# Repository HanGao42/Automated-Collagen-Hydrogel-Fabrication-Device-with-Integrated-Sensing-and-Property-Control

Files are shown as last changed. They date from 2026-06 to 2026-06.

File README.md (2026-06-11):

# Automated Hydrogel Production Platform

This project is a modular hardware and software platform for automated hydrogel production. It coordinates liquid loading, valve routing, syringe mixing, pH color checking, gantry deposition, UV curing, and buffer rehydration.

The active control software is in `Software/`. CAD and mechanical design files are kept separately in `CAD/`.

## System Summary

The platform is built from six hardware units:

1. Pumping unit
   - Four source syringes driven by stepper motors.
   - Aspirates source solutions at the start of an experiment.
   - Dispenses selected source solutions into the mixer during transfer.
   - Controlled by an Arduino Mega with a RAMPS 1.4 shield.

2. Outlet selector / valve lift unit
   - Uses stepper motors to lift and lower the outlet tube.
   - The outlet lift motion is implemented and calibrated.
   - The future outlet routing motor is reserved for later mechanical completion.

3. Mixing unit
   - Two mixer syringes, named Z and E1.
   - Rotary valve stages define the fluid path.
   - Stage 1 allows incoming solution to enter mixer syringe Z.
   - Stage 2 connects Z and E1 for push-pull mixing.
   - Stage 3 routes mixed material out for deposition.

4. pH camera unit
   - ESP32 camera reads hydrogel indicator color.
   - The software estimates pH from an RGB/HSV calibration table.
   - The default target pH is 7.4.
   - During control-flow pH checks, the camera takes five readings, averages them, reports the average, and turns off.

5. Deposition gantry
   - XY gantry draws a small circle while depositing material.
   - This spreads viscous material and prevents a cone-shaped pileup.
   - The gantry and mixer Z/E1 pumps share one Arduino Mega + RAMPS board, which allows synchronized gantry motion and E1 dispensing.

6. UV curing unit
   - Arduino Uno and relay module control UV power.
   - The controller accepts timed `start <seconds>` commands and immediate `stop`.

## Main Hardware

- Arduino Mega 2560 with RAMPS 1.4 shield for the four-syringe pumping unit.
- Arduino Mega 2560 with RAMPS 1.4 shield for the outlet lift / selector valve unit.
- Arduino Mega 2560 with RAMPS 1.4 shield for the deposition gantry and mixer syringe pumps.
- Arduino Uno with relay module for UV light control.
- Freenove ESP32-S3 WROOM camera board for pH color measurement.
- Stepper motors and stepper drivers for syringe plungers, valve motion, and XY gantry motion.
- Four source syringes on the pumping board.
- Two small mixer syringes on the gantry/mixing board.
- UV light source connected through the relay module.

## Default Serial Ports

The current software defaults are:

- Pumping unit: `COM9`
- Outlet selector / valve lift: `COM8`
- Deposition gantry and mixer pumps: `COM7`
- pH camera: `COM5`
- UV relay controller: `COM4`
- Baud rate: `115200`

These ports can be changed in the UI settings page or by command-line options.

## Software Structure

```text
Software/
  central_controller.py
  central_ui.py
  central_command_reference.txt
  ph_color_calibration_table.csv

  pumping_unit/
    syringe_pump_cli.py
    syringe_pump_ramps_controller/
      syringe_pump_ramps_controller.ino
    pumping_state.json

  mixing/
    outlet_flange_valve_controller.py
    outlet_flange_valve_ramps_controller/
      outlet_flange_valve_ramps_controller.ino
    outlet_flange_valve_state.json
    mixing_pump_state.json

  deposition_gantry/
    deposition_gantry_controller.py
    deposition_gantry_ramps_controller/
      deposition_gantry_ramps_controller.ino
    deposition_gantry_state.json

  ph_camera/
    esp32_ph_camera/
      esp32_ph_camera.ino

  uv_curing/
    uv_relay_controller.ino

  ML_model/
    validation and exploratory model files
```

## Code Logic

The project uses four software layers.

### Arduino firmware

The `.ino` files are the lowest hardware-control layer. They run directly on the Arduino or ESP32 boards and convert serial text commands into physical actions.

Firmware responsibilities:

- Configure RAMPS pins, stepper driver enable pins, STEP pins, and DIR pins.
- Generate motor pulses for syringe, valve, and gantry movement.
- Control the UV relay.
- Read camera RGB/HSV data on the ESP32.
- Return readable status lines and `OK` messages to Python.
- Handle emergency commands such as `STOP` and `UNLOCK`.

The Arduino firmware does not know the full hydrogel workflow. It only performs direct hardware actions requested by Python.

### Unit Python scripts

The unit Python scripts are the hardware wrapper layer. They send serial commands to one board and maintain software-side state where needed.

- `pumping_unit/syringe_pump_cli.py`
  - Controls the four source syringe pumps.
  - Stores syringe size and current volume in `pumping_state.json`.
  - Checks syringe capacity before aspirating or dispensing.

- `mixing/outlet_flange_valve_controller.py`
  - Controls outlet lift and mixing valve stages.
  - Stores known/unknown valve state in `outlet_flange_valve_state.json`.
  - Prevents relative stage moves when the saved valve state is unknown.

- `deposition_gantry/deposition_gantry_controller.py`
  - Controls XY gantry motion and mixer Z/E1 pump commands.
  - Stores gantry position in `deposition_gantry_state.json`.
  - Sends mixer pump commands and synchronized gantry-deposition commands to the gantry RAMPS board.

### Central controller

`Software/central_controller.py` is the orchestration layer. It does not directly toggle step pins. Instead, it calls the unit scripts or opens simple serial devices, then coordinates them into guarded workflow steps.

Central controller responsibilities:

- Parse high-level commands such as `flow transfer`, `flow mix-cycle`, `flow ph-check`, and `flow deposit`.
- Check pumping syringe limits before source transfer.
- Check mixer Z/E1 limits before mixing or deposition.
- Require the correct mixing valve stage before each flow step.
- Run some unit commands in software parallel when two boards must act together.
- Read and compare pH camera data against `ph_color_calibration_table.csv`.
- Stop pH camera automatically after flow pH checks.
- Control timed UV exposure through the UV relay Arduino.

Examples:

```bash
cd Software
python central_controller.py pump status
python central_controller.py flow transfer x 2
python central_controller.py flow mix-cycle
python central_controller.py flow ph-check
python central_controller.py flow deposit 1
python central_controller.py uv start 5
```

### Graphical UI

`Software/central_ui.py` is a Tkinter interface on top of `central_controller.py`.

The UI is not an independent control system. It builds central-controller commands, runs them as child Python processes, and displays their terminal output.

The UI has:

- Settings page for COM ports, pH gate values, and dry-run mode.
- Unit Test page for independent hardware checks.
- Control page for the ordered hydrogel workflow.
- Flow buttons arranged in experiment order.
- Live state panels for pumping, selector, mixing, deposition, UV, and pH.
- Terminal report panel showing command output.

## Gantry Control Details

The deposition gantry firmware is in:

```text
Software/deposition_gantry/deposition_gantry_ramps_controller/deposition_gantry_ramps_controller.ino
```

The gantry uses a classic CoreXY-style motion model with two coupled motors:

```text
Motor A = X + Y
Motor B = X - Y
```

In the firmware this appears as:

```cpp
long aSteps = xSteps + ySteps;
long bSteps = xSteps - ySteps;
```

This means an X/Y movement is first converted to X and Y step counts, then transformed into Motor A and Motor B step counts. The firmware then pulses each motor by the required number of steps.

Important implementation points:

- The gantry does not use the full Marlin firmware.
- It does not use the AccelStepper library for the gantry motion.
- The motion planning is custom and lightweight, using RAMPS STEP/DIR pins directly.
- The implementation is inspired by common 3D-printer/CNC motion concepts:
  - STEP pulse generation.
  - DIR pin direction control.
  - Soft travel limits.
  - A simple trapezoid-style acceleration profile.
  - Manual logical zero with `SETZERO`.

The STEP pulse function is intentionally simple:

```cpp
void pulseMotor(byte stepPin) {
  digitalWrite(stepPin, HIGH);
  delayMicroseconds(STEP_HIGH_US);
  digitalWrite(stepPin, LOW);
}
```

For each step, the firmware raises the STEP pin, waits a few microseconds so the stepper driver can detect the edge, then lowers the pin again.

The gantry firmware also handles synchronized commands:

- `PUMP PAIR ZS0.1 E1S-0.1`
  - Moves mixer syringes Z and E1 at the same time.
  - Used for push-pull mixing without the delay caused by sequential commands.

- `GANTRY DEPOSIT X30 Y30 R8 V0.5 N120 L1`
  - Draws a circular gantry path while dispensing from mixer syringe E1.
  - Used during deposition so the gantry and E1 syringe move together on the same RAMPS board.

## Production Workflow

The intended automated workflow is:

1. Fill the selected pumping syringe with source solution.
2. Move the mixing valve to Stage 1.
3. Transfer solution from the pumping unit into mixer syringe Z.
4. Disable pumping motors if they are no longer needed, to reduce heating.
5. Move the mixing valve to Stage 2.
6. Run synchronized Z/E1 push-pull mixing cycles.
7. Turn on the pH camera, take five color readings, average them, and compare the average with the pH table.
8. If pH is acceptable, transfer the required volume from mixer Z to E1.
9. Move the mixing valve to Stage 3.
10. Deposit the hydrogel while the gantry draws a circle and E1 dispenses.
11. Return the gantry to origin.
12. Wait for gelation.
13. Run UV curing for the chosen duration.
14. Inject buffer through the mixer path.
15. Deposit buffer back onto the gel position for hydration.

## Safety and Limit Checks

The central controller checks:

- Pumping syringe capacity before aspirating.
- Pumping syringe current volume before dispensing.
- Mixer Z/E1 capacity before aspirating.
- Mixer Z/E1 current volume before dispensing.
- Required mixing valve stage before transfer, mixing, and deposition.
- Gantry position state before movement.
- Positive volume values for flow operations.
- pH camera timeout and automatic camera shutdown after flow pH checks.
- UV exposure duration must be positive for timed starts.

The Arduino firmware also includes:

- Emergency `STOP` and `UNLOCK` commands on motor boards.
- Gantry soft limits for X/Y travel.
- Circle segment and loop limits.
- Pump speed limits.

Direct Arduino Serial Monitor commands can bypass some Python-side state checks. For normal experiments, use the UI or `central_controller.py`.

## State Files

The JSON state files store software-side known positions and syringe contents:

- `pumping_unit/pumping_state.json`
- `mixing/mixing_pump_state.json`
- `mixing/outlet_flange_valve_state.json`
- `deposition_gantry/deposition_gantry_state.json`

These files must match the real hardware state before automated flow commands are used.

Use set-zero commands only when the hardware is physically at the corresponding zero state. If hardware is moved by hand, update the software state before running automatic commands.

## Arduino Firmware Uploads

Upload the following sketches to the matching boards:

- Pumping unit Mega/RAMPS:
  - `Software/pumping_unit/syringe_pump_ramps_controller/syringe_pump_ramps_controller.ino`

- Outlet lift / selector Mega/RAMPS:
  - `Software/mixing/outlet_flange_valve_ramps_controller/outlet_flange_valve_ramps_controller.ino`

- Deposition gantry and mixer pumps Mega/RAMPS:
  - `Software/deposition_gantry/deposition_gantry_ramps_controller/deposition_gantry_ramps_controller.ino`

- pH camera ESP32:
  - `Software/ph_camera/esp32_ph_camera/esp32_ph_camera.ino`

- UV relay Arduino Uno:
  - `Software/uv_curing/uv_relay_controller.ino`

All active controllers use `115200` baud.

## pH Calibration

The pH camera uses:

```text
Software/ph_color_calibration_table.csv
```

The central controller estimates pH by comparing the averaged RGB/HSV reading against this calibration table. The current target pH is 7.4.

The pH result is used as a process check. The current system reports whether the measured color is within the target range. Full acid/base automatic correction logic is reserved for future development.

## Installation

Install Python 3.12 or another recent Python 3 version.

Install the main runtime dependency:

```bash
pip install -r requirements.txt
```

Tkinter is included with the standard Windows Python installer.

Arduino IDE requirements:

- Install the `AccelStepper` library for the pumping unit sketch.
- Install the ESP32 board package for the Freenove ESP32-S3 pH camera sketch.
- The gantry, selector, and UV sketches otherwise use standard Arduino APIs.

## Running the UI

```bash
cd Software
python central_ui.py
```

Check COM port settings before running real hardware. The UI starts in dry-run mode by default. Uncheck dry-run only after confirming the ports, uploaded firmware, and physical hardware state.

## ML_model Folder

`Software/ML_model/` contains a validation / exploratory model. It is not part of the main hardware control loop. The model currently has large prediction error, so it should be treated only as a rough verification or analysis attempt rather than a production control component.

The ML folder has its own optional dependency list. These packages are not required to run the main automation system.

## User Manual Notes

A separate user manual should focus on operation rather than code. It should include:

- Hardware setup and wiring checks.
- Firmware upload order.
- COM port setup.
- How to initialize saved syringe volumes and gantry zero.
- How to use Unit Test safely.
- How to run the Control workflow.
- How to interpret pH, UV, and terminal messages.
- Emergency stop and recovery procedure.
- Common troubleshooting cases.

## Notes

- Keep saved JSON state files aligned with physical syringe contents and gantry position.
- Use the Unit Test page before running the full Control workflow.
- Keep dry-run enabled until ports and firmware are verified.
- The outlet routing motor logic is reserved for future mechanical completion.
- The command reference is available in `Software/central_command_reference.txt`.

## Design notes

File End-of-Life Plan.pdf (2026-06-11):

## End-of-Life Plan

This prototype was designed as a modular system. The main subsystems can be separated from each other, including the mixing chamber, the syringe pumping system, the pH sensing system, the CoreXY deposition gantry, the heating system, the UV crosslinking system and the control electronics. Because of this modular design, the preferred end-of-life route is not disposal. The priority is to keep the prototype, or its useful modules, for future student projects and further research. The first option is to hand over the complete prototype to future students. This is the preferred route if

the device is still structurally safe and the main modules are still working. Future students can continue the development of the full hydrogel fabrication process, including real collagen testing, improved pH calibration, gantry accuracy validation, UV safety improvement and closed-loop process control. The submitted CAD files, code, risk assessments and unused material list should be kept with the prototype so that the next users can understand the current design status. The second option is to let the university reuse separate modules for other teaching or research

projects. If the complete prototype is not needed, the system should be dismantled into reusable modules. For example, the CoreXY gantry can be reused for motion control or deposition projects. The Arduino boards, sensors and camera modules can be reused for control, image processing or sensing projects. Motors, bearings, screws and brackets can also be reused in future mechanical prototypes. If a component cannot be reused, it should be recycled or disposed of through the correct route. Electrical parts should not be placed in normal waste. Parts that have contacted collagen, NaOH, riboflavin or buffer solution should only be reused if they can be cleaned safely. If they are

contaminated, damaged or difficult to clean, they should be disposed of through the appropriate laboratory waste route. Position: MechSpace, Plastic Box B42 and B41. Collagen Solution in 3

rd

floor. Prototype part or module | Preferred end-of-life action | Alternative action if not reused
Complete prototype | Keep as a full system for future students to continue the project. It can support further work on collagen mixing, pH control, gel Keep for future hydrogel or deposition, UV crosslinking and validation. | If the full system is no longer needed, separate it into reusable modules before any disposal is considered. Mixing chamber
| preparation or mixing tests. temperature-sensitive fluid projects. The chamber can be reused, syringe- based | Return to the department or dispose of through the approved electrical appliance route if it is damaged. Syringe pumps, valve system
and fluidic routing | modules. Reuse for future microfluidic, mixing or dosing projects. Clean parts should be kept with the prototype as spare fluidic Reuse as a motion platform for | Tubing, syringes and connectors that are used, worn or contaminated should be disposed of through the correct lab waste route. CoreXY deposition gantry
| deposition, printing, scanning or positioning projects. Motors, belts, rails, bearings and | If dismantled, working motors and mechanical parts should be stored for future projects. Damaged plastic or acrylic parts

Prototype part or module | Preferred end-of-life action | Alternative action if not reused
| functional. brackets should be kept if | should be disposed of according to workshop procedure. pH sensing and optical sensing
system | Reuse the camera, colour sensor, LEDs and control board for future pH calibration, colour detection or image processing work. Reuse Raspberry Pi, Arduino | If electronic parts fail, dispose of them through the electronic waste route. Optical mounts or brackets can be reused if still intact. Control electronics and wiring
| be kept if it is still safe and clear. boards, ESP32 boards, motor drivers, breadboards and sensors in future student Reuse the heating mat and projects. Labelled wiring should | Damaged boards, loose unsafe wires or broken electrical parts should be removed and disposed of as electronic waste. Heating system
| temperature control parts for future gelation or temperature- control experiments if they pass safety checks. Keep the UV lamp, enclosure | If the heating mat, relay or power connection is damaged, it should not be reused. It should be disposed of through the correct electrical waste route. UV crosslinking system
| and shielding for future controlled crosslinking tests if the system is still safe. The enclosure should remain labelled as a UV safety component. | If the UV lamp or shielding is damaged, the system should not be operated. The lamp and electrical parts should be disposed of through the correct route. Structural frame, acrylic panels
and 3D printed parts | rebuilding the full system. Reuse intact panels, brackets and printed parts for future prototype changes. The modular design allows parts to be removed and replaced without | Damaged acrylic, PLA or other plastic parts should be disposed of through the workshop waste route. Metal parts should be recycled where possible. Fluid-contact parts exposed to
collagen, NaOH, riboflavin or buffer | labelled before storage. Reuse only if the parts can be cleaned safely and are still suitable for laboratory use. Cleanable parts should be Keep CAD files, code, risk | Contaminated, blocked or single-use parts should be disposed of through the approved lab waste route. They should not be returned to general storage. Documentation and digital files
| assessments, test results, calibration data and operating notes with the physical prototype. This helps future users understand what has been built and what still needs validation. | If the prototype is dismantled, the files should still be stored by the department or project supervisor as a record of the design and testing work.

Clean unused materials are listed separately in the unused material list. These materials should be kept for future student projects where possible. If any unused material becomes damaged, expired or unsuitable for reuse, it should be disposed of through the relevant workshop, laboratory or electronic waste route. Overall, the recommended end-of-life approach is to reuse first, then recycle, and only dispose of parts

when reuse or recycling is not suitable. This approach reduces waste and also allows future students or the school to gain value from the modules, components and documentation developed in this project.

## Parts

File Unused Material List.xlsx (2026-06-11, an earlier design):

Unused Material List
Part Description | Quantity | Cost (inc. VAT) Each | Cost (inc. VAT) Total | Condition | Suggested Future Use
Assorted nuts and bolts | 1 | £10.00 | £10.00 | Partially unused / clean; check thread compatibility before reuse | General mechanical assembly, replacement fasteners and future prototype modifications
6 well plate, TC treated, sterile, individually wrapped, with lid, Corning | 1 | £37.86 | £37.86 | Mostly unopened / sterile while sealed; check packaging and expiry before lab use | Future collagen hydrogel preparation, calibration samples or gelation tests
pH indicator solution | 2 | £14.97 | £29.94 | Unused / sealed if unopened; check expiry and contamination before reuse | Colourimetric pH calibration and indicator-based pH sensing tests
Breadboard Kit. Breadboard + Jumping Wires | 1 | £12.99 | £12.99 | Breadboards unused; jumper wires partially remaining and reusable | Electronics prototyping, temporary wiring and sensor/motor driver testing
Raspberry Pi 5 Board | 1 | £43.20 | £43.20 | Functional reusable electronics; check boot and power supply before reuse | Main controller or image-processing platform for future optical sensing/GUI development
Raspberry Pi Camera Module 3 | 1 | £24.00 | £24.00 | Functional reusable camera module; check ribbon cable and lens condition | Colour/pH sensing, image capture and calibration testing
DMEM, high glucose, HEPES, 500 mL-Each | 1 | £10.21 | £10.21 | Unused / sealed if unopened; store according to supplier instructions and check expiry | Future buffer/media testing, pH calibration validation and collagen preparation work
DTGN M3-0.5x10mm Flat Head Socket Cap Screws | 1 | £4.29 | £4.29 | Partially unused / clean | Replacement countersunk screws for enclosure, brackets and mechanical assembly
100Pcs M3 3mm Female Thread Hex Metal Nut | 1 | £4.39 | £4.39 | Partially unused / clean | Replacement M3 nuts for future assembly and maintenance
12Pcs LM6UU Linear Ball Bearings | 1 | £11.99 | £11.99 | Partially unused / clean; check smooth motion before reuse | Linear motion support for gantry/deposition mechanism or spare bearing replacement
Tee Wing Knobs Thumb Screws M5 x 40mm Standard Male | 1 | £6.69 | £6.69 | Partially unused / clean | Manual fastening/adjustment points for prototype fixtures
20 Pcs M3-0.5 x 20mm Hex Socket Head Screws | 1 | £5.09 | £5.09 | Partially unused / clean | Replacement screws for frame, gantry and bracket assembly
(28*15cm) heating mat | 1 | £8.99 | £8.99 | Unused / functional; electrical safety check before reuse | Temperature-control testing or small-area gelation chamber heating
(28*28cm) heating mat | 1 | £8.99 | £8.99 | Unused / functional; electrical safety check before reuse | Larger-area heating for deposition chamber or gelation tests

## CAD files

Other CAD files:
CAD/selection_valve_v1.f3z
CAD/selection_valve_v2.f3z

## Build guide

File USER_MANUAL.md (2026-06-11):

# User Manual

## Purpose

This manual explains how to set up, test, and operate the automated hydrogel production platform. It is written for daily operation, hardware checking, and troubleshooting.

The main rule is:

```text
The software state must match the real hardware state before using the Control page.
```

The UI can track syringe volumes, valve stage, gantry position, UV history, and pH readings, but most of these values are software records. If the hardware is moved by hand, disconnected, refilled, emptied, or reset, the software state must be updated before automatic control.

## Board Map

The system uses three Arduino Mega + RAMPS 1.4 boards, one Arduino Uno, and one ESP32 camera.

### Mega + RAMPS 1: Pumping Unit

This board controls the four source syringe pumps.

```text
RAMPS X motor socket  -> pumping syringe X
RAMPS Y motor socket  -> pumping syringe Y
RAMPS Z motor socket  -> pumping syringe Z
RAMPS E1 motor socket -> pumping syringe E1
```

All four source syringe motors are connected to this first Mega + RAMPS board.

### Mega + RAMPS 2: Selector / Valve Unit

This board controls the outlet lift and mixing valve motors.

```text
RAMPS Z motor socket -> outlet lift motor
RAMPS X motor socket -> mixing valve X motor
RAMPS Y motor socket -> mixing valve Y motor
```

The outlet lift motor is implemented and calibrated. The future outlet routing / selection motor is reserved for later mechanical completion.

### Mega + RAMPS 3: Deposition Gantry and Mixer Pumps

This board controls the XY gantry and the two mixer syringes.

```text
RAMPS X motor socket  -> gantry CoreXY motor A
RAMPS Y motor socket  -> gantry CoreXY motor B
RAMPS Z motor socket  -> mixer syringe Z
RAMPS E1 motor socket -> mixer syringe E1
```

The gantry and mixer pumps share one board so that deposition can synchronize circular gantry motion with E1 syringe dispensing.

### Arduino Uno: UV Relay

The Uno controls the UV relay.

Typical relay control wiring:

```text
Uno GND -> relay GND
Uno 5V  -> relay VCC
Uno D8  -> relay signal input
```

The relay power side depends on the UV power supply. Use the relay COM/NO contacts according to the relay module and UV supply wiring.

### ESP32: pH Camera

The ESP32 camera is connected to the PC by USB. It reads RGB/HSV color data and sends readings to the central controller through serial.

## RAMPS Motor Socket Rule

This project only uses the RAMPS motor sockets:

```text
X, Y, Z, E1
```

Do not assume other motor outputs are used unless the firmware is changed.

## Software Installation

Install Python 3.12 or another recent Python 3 version.

From the project root:

```bash
pip install -r requirements.txt
```

The main Python dependency is `pyserial`. Tkinter is included with the normal Windows Python installer.

## Firmware Upload

Upload each firmware file to the matching board with Arduino IDE.

```text
Pumping Mega/RAMPS:
Software/pumping_unit/syringe_pump_ramps_controller/syringe_pump_ramps_controller.ino

Selector / valve Mega/RAMPS:
Software/mixing/outlet_flange_valve_ramps_controller/outlet_flange_valve_ramps_controller.ino

Gantry + mixer pump Mega/RAMPS:
Software/deposition_gantry/deposition_gantry_ramps_controller/deposition_gantry_ramps_controller.ino

pH camera ESP32:
Software/ph_camera/esp32_ph_camera/esp32_ph_camera.ino

UV relay Uno:
Software/uv_curing/uv_relay_controller.ino
```

All active serial controllers use:

```text
115200 baud
```

## Default COM Ports

The current default ports are:

```text
Pumping unit: COM9
Selector / valve unit: COM8
Gantry + mixer pumps: COM7
pH camera: COM5
UV relay: COM4
```

If Windows assigns different COM ports, change them in the UI Settings page.

## Starting the UI

From the project root:

```bash
cd Software
python central_ui.py
```

The UI has three main pages:

```text
Settings  -> COM ports, pH gate, dry-run setting
Unit Test -> independent testing for each unit
Control   -> ordered hydrogel production workflow
```

## Dry-run Mode

Dry-run mode is for checking the UI and command generation.

In dry-run mode:

- The UI still builds central-controller commands.
- The terminal report still shows what would be run.
- No real serial command is sent to the hardware.
- Motors, camera, and UV should not move or turn on.

Dry-run can confirm that the UI buttons and command paths are working, but it cannot prove the hardware is working.

For real hardware testing, turn dry-run off and use the Unit Test page.

## Recommended Setup Order

Use this order when setting up the system.

1. Assemble each unit separately.
2. Upload the correct firmware to each board.
3. Connect each board to the PC.
4. Open the UI.
5. Check and update COM ports in Settings.
6. Keep dry-run on and press several buttons to check the UI command path.
7. Turn dry-run off.
8. Use Unit Test to test each unit independently.
9. Connect tubing and fluid paths after independent unit tests pass.
10. Synchronize software state with real hardware state.
11. Use the Control page for the full workflow.

## Unit Test Page

Use Unit Test before running the Control page.

Recommended checks:

- Pumping unit:
  - Confirm each source syringe motor can move.
  - Confirm aspirate and dispense directions are correct.
  - Confirm current syringe volume records are correct.

- Selector / valve unit:
  - Confirm outlet lift up/down motion.
  - Confirm mixing valve Stage 1, Stage 2, and Stage 3 movement.
  - Confirm the software stage matches the physical valve stage.

- Mixing pumps:
  - Confirm mixer syringe Z can move in both directions.
  - Confirm mixer syringe E1 can move in both directions.
  - Confirm synchronized Z/E1 pair motion works.

- Deposition gantry:
  - Confirm X/Y gantry motion.
  - Move the gantry to the physical origin and use set zero.
  - Confirm circle drawing motion.
  - Confirm synchronized deposition motion if fluid testing is safe.

- pH camera:
  - Confirm camera can turn on.
  - Confirm color and estimated pH are printed.
  - Confirm camera turns off after the check.

- UV:
  - Confirm a short timed exposure such as 5 seconds.
  - Confirm stop turns UV off immediately.

## State Synchronization

The UI status panel shows software-side state. It must match the real machine.

Important state values:

```text
Pumping syringes: current liquid volume in X/Y/Z/E1
Mixing syringes: current liquid volume in Z/E1
Mixing valve: current stage
Gantry: current X/Y position
pH: latest measured color and estimated pH
UV: current on/off state and exposure history
```

Before using the Control page:

1. Confirm the real source syringe volumes.
2. Set pumping syringe records to match the real volumes.
3. Confirm the real mixer Z/E1 volumes.
4. Use mixer syringe set-zero only when the real mixer syringes are empty.
5. Confirm the physical mixing valve stage.
6. Set the software valve stage to match the real valve stage.
7. Move the gantry to the physical origin.
8. Use gantry set zero only at the real origin.

If any displayed state is unknown, stop and resynchronize before using automatic flow buttons.

## Control Page Workflow

The Control page is arranged in the expected production order. In normal operation, press the buttons from top to bottom, then check the right-side status panel and terminal report after each step.

Typical workflow:

1. Aspirate source solution into the required pumping syringe.
2. Move the mixing valve to Stage 1.
3. Transfer source solution from the pumping unit into mixer syringe Z.
4. Disable pumping motors if they are no longer needed.
5. Move the mixing valve to Stage 2.
6. Run flow mix cycles with synchronized Z/E1 push-pull motion.
7. Run pH camera check.
8. If pH is acceptable, transfer material from mixer Z to E1.
9. Move the mixing valve to Stage 3.
10. Run deposition with synchronized gantry circle and E1 dispense.
11. Return gantry to origin.
12. Wait for gelation.
13. Run UV curing.
14. Add buffer through the mixer path.
15. Deposit buffer back onto the hydrogel area.

The Control page includes logic checks. For example:

- Pumping-to-mixer transfer should only run when the mixing valve is at Stage 1.
- Mixing cycles should only run when the mixing valve is at Stage 2.
- Deposition should only run when the mixing valve is at Stage 3.
- Pump and mixer syringe volumes are checked before motion.

## Status Panel

The status panel summarizes known software state.

Color meaning:

```text
Green text -> known state
Red text   -> unknown state
Black text -> informational value without known/unknown flag
```

Do not continue automatic workflow steps when an important unit state is unknown.

## pH Check

The pH camera check turns the camera on, takes five readings, averages them, prints the averaged color and estimated pH, then turns the camera off.

The pH calibration table is:

```text
Software/ph_color_calibration_table.csv
```

The default target pH is:

```text
7.4
```

The pH result is a color-based estimate. It should be interpreted together with experimental judgment and calibration quality.

## UV Curing

The UV page buttons send timed `start` commands or immediate `stop` commands to the Uno relay controller.

Use a short test exposure first, such as 5 seconds.

Safety notes:

- Do not look directly at UV light.
- Keep UV exposure shielded.
- Use `stop` immediately if the relay or UV behavior is unexpected.

## Emergency Stop and Recovery

Motor boards support emergency stop behavior through firmware commands.

After emergency stop:

1. Motion stops and motors may be disabled.
2. Some software states may become unknown.
3. Clear the hardware stop state with `UNLOCK` only after checking the machine.
4. Reconfirm physical position, valve stage, and syringe volumes.
5. Re-enter or reset software state before continuing.

If the UI reports a command failure, read the terminal report before pressing more control buttons.

## Manual Serial Monitor Tests

These commands can be typed in Arduino IDE Serial Monitor when testing one board directly. Use `115200 baud`.

UV relay Uno:

```text
start 5
stop
```

Gantry + mixer board:

```text
GANTRY SETZERO
GANTRY GOTO X30 Y30
GANTRY CIRCLE X30 Y30 R10 N120 L1
PUMP PAIR ZS0.1 E1S-0.1
GANTRY DEPOSIT X30 Y30 R10 V1 N120 L1
STOP
UNLOCK
```

Selector / valve board:

```text
UP
DOWN
MIX_X_CW90
MIX_X_CCW90
MIX_Y_CW180
MIX_Y_CCW180
STOP
UNLOCK
```

Pumping board:

```text
XS1
XS-1
YL1
ZL-1
E1S0.5
STOP
```

## Troubleshooting

### COM port permission denied

Possible causes:

- Arduino IDE Serial Monitor is open.
- Another Python process is using the same port.
- The board was unplugged and replugged with a new COM number.

Fix:

1. Close Arduino Serial Monitor.
2. Close other running UI or Python windows.
3. Check Device Manager for the current COM port.
4. Update the UI Settings page.

### Motor does not move

Check:

- Correct board and COM port.
- Correct firmware uploaded.
- RAMPS power connected.
- Stepper driver installed and oriented correctly.
- Motor plugged into the correct X/Y/Z/E1 socket.
- Dry-run is off.
- Terminal report does not show an error.

### Motion direction is wrong

Direction can be fixed in firmware by changing the relevant invert constant. Re-upload firmware after changing direction constants.

### pH camera does not print color

Check:

- Correct ESP32 COM port.
- Correct ESP32 firmware uploaded.
- Camera is not already locked by another program.
- The camera has enough light and can see the sample.

### UV relay does not click

Check:

- Correct Uno COM port.
- Correct UV relay firmware uploaded.
- Relay signal wire is connected to D8.
- Relay GND and Uno GND are connected.
- Serial baud is 115200.

### UI status does not match hardware

Stop automatic operation. Manually confirm hardware state, then update the software state using Unit Test or set-zero/set-stage controls.

## Shutdown and Cleaning

After an experiment:

1. Stop UV.
2. Turn off pH camera if it is still active.
3. Disable motors where possible.
4. Save any needed terminal output or experiment notes.
5. Flush or clean tubing.
6. Clean syringes.
7. Remove or seal samples.
8. Disconnect power supplies when safe.

## Final Operating Reminder

Use Unit Test to prove each unit works alone. Use Control only after hardware state and software state agree. During Control operation, press buttons in order, watch the status panel, and read the terminal report after each command.

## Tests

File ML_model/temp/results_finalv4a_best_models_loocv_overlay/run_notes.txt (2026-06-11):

This overlay plot compares the generalization performance of the best GPR model and the best Polynomial model.
The data in this folder come from LOOCV prediction files, so each point is an out-of-sample prediction.
Best GPR model: GPR_Matern15
Best Polynomial model: Poly2_Linear
Output CSV: best_models_loocv_predictions_overlay.csv
Output figure: Fig_best_gpr_vs_best_polynomial_loocv_overlay_true_vs_pred.png

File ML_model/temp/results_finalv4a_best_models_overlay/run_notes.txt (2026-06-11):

Input file: finalv4a.xlsx\nGPR model file: best_gpr_final_model.joblib\nPolynomial model file: best_polynomial_final_model.joblib\nThese predictions are generated by the final exported best models fitted on the full dataset.\nThis is not LOOCV prediction data.\nOutput CSV: best_models_predictions_overlay.csv\nOutput figure: Fig_best_gpr_vs_best_polynomial_overlay_true_vs_pred.png

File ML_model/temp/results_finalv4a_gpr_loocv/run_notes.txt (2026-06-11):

Input file: finalv4a.xlsx
Number of valid rows used: 9
Validation method: LOOCV
Features: ['Collagen_mg_mL', 'UV_min']
Target: Shear_kPa
Scaling approach: fold-wise StandardScaler on X and y during LOOCV.
Best GPR model by RMSE: GPR_Matern15 (RMSE=1.531584, MAE=1.053724, R2=0.658117)
Exported model file: best_gpr_final_model.joblib

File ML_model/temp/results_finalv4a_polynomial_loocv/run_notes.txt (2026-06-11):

Input file: finalv4a.xlsx
Number of valid rows used: 9
Validation method: LOOCV
Features: ['Collagen_mg_mL', 'UV_min']
Target: Shear_kPa
Scaling approach: fold-wise StandardScaler on X and y during LOOCV.
Polynomial coefficient files are saved in both standardized basis and raw-unit basis.
Best Polynomial model by RMSE: Poly2_Linear (RMSE=0.997325, MAE=0.700521, R2=0.855033)
Exported model file: best_polynomial_final_model.joblib

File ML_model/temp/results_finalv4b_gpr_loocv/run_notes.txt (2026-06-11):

Input file: finalv4b.xlsx
Number of valid rows used: 14
Validation method: LOOCV
Features: ['Collagen_mg_mL', 'UV_min']
Target: Shear_kPa
Scaling approach: fold-wise StandardScaler on X and y during LOOCV.
Best GPR model by RMSE: GPR_Matern15 (RMSE=0.775262, MAE=0.646148, R2=0.912806)
Exported model file: best_gpr_final_model.joblib

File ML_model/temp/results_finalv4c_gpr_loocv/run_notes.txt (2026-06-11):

Input file: finalv4c.xlsx
Number of valid rows used: 42
Validation method: LOOCV
Features: ['Collagen_mg_mL', 'UV_min']
Target: Shear_kPa
Scaling approach: fold-wise StandardScaler on X and y during LOOCV.
Best GPR model by RMSE: GPR_Matern05 (RMSE=4.135766, MAE=2.085546, R2=0.181490)
Exported model file: best_gpr_final_model.joblib

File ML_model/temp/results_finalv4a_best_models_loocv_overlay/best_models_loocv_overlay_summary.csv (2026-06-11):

family | model | RMSE | MAE | R2 | n_samples
Polynomial | Poly2_Linear | 0.9973251801928354 | 0.7005214209075137 | 0.8550328620815009 | 9
GPR | GPR_Matern15 | 1.5315837709933628 | 1.0537236479179626 | 0.6581169985008153 | 9

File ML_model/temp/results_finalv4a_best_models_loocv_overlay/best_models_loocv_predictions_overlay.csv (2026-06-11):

fold | model | true | pred | pred_std | abs_error | sq_error | family
1 | GPR_Matern15 | 0.5333333333333333 | 1.5830730581692722 | 0.6762744189054698 | 1.049739724835939 | 1.101953489898633 | GPR
2 | GPR_Matern15 | 3.9 | 4.3804633331573655 | 0.5222538613736675 | 0.4804633331573655 | 0.2308450145086856 | GPR
3 | GPR_Matern15 | 1.6333333333333335 | 1.3464581498053063 | 0.3144562864362677 | 0.286875183528027 | 0.0822973709242391 | GPR
4 | GPR_Matern15 | 5.366666666666667 | 5.225882027868795 | 0.3455493286817773 | 0.1407846387978724 | 0.0198203145214473 | GPR
5 | GPR_Matern15 | 2.2666666666666666 | 4.05336305966158 | 0.5919071689493969 | 1.7866963929949131 | 3.192284000741033 | GPR
6 | GPR_Matern15 | 5.666666666666667 | 4.458893612051676 | 0.2994344739360751 | 1.2077730546149912 | 1.4587157514540263 | GPR
7 | GPR_Matern15 | 6.433333333333334 | 6.759586099329601 | 0.5087256225492998 | 0.3262527659962675 | 0.1064408673202153 | GPR
8 | GPR_Matern15 | 8.1 | 4.2541666666666735 | 2.970056653744713 | 3.845833333333326 | 14.790434027777724 | GPR
9 | GPR_Matern15 | 8.233333333333333 | 7.874238929330371 | 3.0799021541040914 | 0.3590944040029615 | 0.1289487909862421 | GPR
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

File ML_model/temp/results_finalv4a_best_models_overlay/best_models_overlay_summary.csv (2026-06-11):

family | model | RMSE | MAE
GPR | GPR_Matern15 | 1.4521590813799605e-05 | 1.2629612830032203e-05
Polynomial | Poly2_Linear | 0.3153168636604723 | 0.210337713451406

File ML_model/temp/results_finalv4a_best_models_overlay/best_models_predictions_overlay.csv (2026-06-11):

sample_id | model | family | true | pred | pred_std | abs_error | sq_error
1 | GPR_Matern15 | GPR | 0.5333333333333333 | 0.5333479991209069 | 0.002619364427167176 | 1.466578757358672e-05 | 2.1508532515357064e-10
2 | GPR_Matern15 | GPR | 3.9 | 3.900012719387873 | 0.0026193636175352855 | 1.2719387873172394e-05 | 1.6178282786820496e-10
3 | GPR_Matern15 | GPR | 1.6333333333333335 | 1.6333093740696376 | 0.002619279941427906 | 2.3959263695916277e-05 | 5.740463168504518e-10
4 | GPR_Matern15 | GPR | 5.366666666666667 | 5.366652393514058 | 0.0026192785094033035 | 1.4273152609156625e-05 | 2.0372288540427457e-10
5 | GPR_Matern15 | GPR | 2.2666666666666666 | 2.26668640441885 | 0.0026193614346687478 | 1.973775218333529e-05 | 3.8957886125075695e-10
6 | GPR_Matern15 | GPR | 5.666666666666667 | 5.666650949602083 | 0.002619386519784478 | 1.5717064584030993e-05 | 2.470261191386013e-10
7 | GPR_Matern15 | GPR | 6.433333333333334 | 6.433343390721624 | 0.0026193559690607534 | 1.0057388290185543e-05 | 1.0115105921956127e-10
8 | GPR_Matern15 | GPR | 8.1 | 8.099997664276579 | 0.0026193981581170878 | 2.3357234208987165e-06 | 5.455603898934803e-12
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

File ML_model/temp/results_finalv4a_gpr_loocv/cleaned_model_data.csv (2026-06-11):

Collagen_mg_mL | UV_min | Shear_kPa
10.0 | 0 | 0.5333333333333333
10.0 | 30 | 3.9
12.5 | 0 | 1.6333333333333335
12.5 | 30 | 5.366666666666667
15.0 | 0 | 2.2666666666666666
15.0 | 15 | 5.666666666666667
15.0 | 30 | 6.433333333333334
15.0 | 60 | 8.1
15.0 | 90 | 8.233333333333333

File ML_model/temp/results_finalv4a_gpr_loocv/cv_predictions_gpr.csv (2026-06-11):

fold | model | true | pred | pred_std | abs_error | sq_error
1 | GPR_RBF | 0.5333333333333333 | 1.5255759293787272 | 0.4375038613947715 | 0.9922425960453939 | 0.9845453694069027
2 | GPR_RBF | 3.9 | 4.370156796109619 | 0.5670836192500252 | 0.4701567961096189 | 0.22104741292806177
3 | GPR_RBF | 1.6333333333333335 | 1.193020901357892 | 0.2441351779339754 | 0.44031243197544145 | 0.19387503775212775
4 | GPR_RBF | 5.366666666666667 | 5.208061392096134 | 0.35198591898981274 | 0.15860527457053308 | 0.02515563312159419
5 | GPR_RBF | 2.2666666666666666 | 5.144653407223784 | 0.19911662057607754 | 2.877986740557118 | 8.282807678822582
6 | GPR_RBF | 5.666666666666667 | 4.594338534995975 | 0.06672420609859556 | 1.0723281316706919 | 1.1498876219723566
7 | GPR_RBF | 6.433333333333334 | 6.471022260855916 | 0.6374392193416567 | 0.03768892752258246 | 0.0014204552578024738
8 | GPR_RBF | 8.1 | 4.254166666666666 | 2.9807860497333842 | 3.845833333333333 | 14.790434027777778
9 | GPR_RBF | 8.233333333333333 | 4.237500000000004 | 2.939816171739847 | 3.9958333333333282 | 15.966684027777736
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

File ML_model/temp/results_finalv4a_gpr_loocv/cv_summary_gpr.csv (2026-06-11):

model | RMSE | MAE | R2 | n_samples
GPR_Matern15 | 1.5315837709933628 | 1.0537236479179626 | 0.6581169985008153 | 9
GPR_Matern25 | 1.6237294934093556 | 1.160755639060756 | 0.6157416133193578 | 9
GPR_RationalQuadratic | 1.829295164124037 | 1.6395658970636815 | 0.5122878566436383 | 9
GPR_Matern05 | 2.1445963097014 | 1.655594916726854 | 0.3296723941243126 | 9
GPR_RBF | 2.1503451212619837 | 1.5434430627908933 | 0.32607381285158477 | 9

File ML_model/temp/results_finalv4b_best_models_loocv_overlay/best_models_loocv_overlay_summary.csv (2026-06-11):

family | model | RMSE | MAE | R2 | n_samples
Polynomial | Poly2_Linear | 0.5640534928856192 | 0.4154878702081854 | 0.9538435616199656 | 14
GPR | GPR_Matern15 | 0.7752617349276756 | 0.6461482542676442 | 0.9128056386293175 | 14

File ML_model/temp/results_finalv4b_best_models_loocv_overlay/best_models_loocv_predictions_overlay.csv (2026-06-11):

fold | model | true | pred | pred_std | abs_error | sq_error | family
1 | GPR_Matern15 | 1.0666666666666669 | 1.4385972538466918 | 0.2190561292161471 | 0.3719305871800251 | 0.1383323616800783 | GPR
2 | GPR_Matern15 | 0.7000000000000001 | 0.248227256962918 | 0.7862097916627488 | 0.451772743037082 | 0.2040986113512493 | GPR
3 | GPR_Matern15 | 1.65 | 1.3280872206781047 | 0.18994566798466 | 0.3219127793218954 | 0.1036278374907473 | GPR
4 | GPR_Matern15 | 1.9 | 1.670840992502671 | 0.6048154819259979 | 0.2291590074973291 | 0.0525138507171609 | GPR
5 | GPR_Matern15 | 1.9333333333333331 | 2.775098338272924 | 1.0886712785260948 | 0.8417650049395908 | 0.7085683235409493 | GPR
6 | GPR_Matern15 | 0.5333333333333333 | 1.0169608977910205 | 0.4356826649761002 | 0.4836275644576869 | 0.2338956211032741 | GPR
7 | GPR_Matern15 | 3.9 | 4.430961338871685 | 0.2125733590277793 | 0.5309613388716854 | 0.2819199433764127 | GPR
8 | GPR_Matern15 | 1.6333333333333335 | 1.3646526288069505 | 0.290664948941953 | 0.268680704526383 | 0.0721893209847935 | GPR
9 | GPR_Matern15 | 5.366666666666667 | 5.1494782266336765 | 0.2673663172161296 | 0.2171884400329906 | 0.0471708184839639 | GPR
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

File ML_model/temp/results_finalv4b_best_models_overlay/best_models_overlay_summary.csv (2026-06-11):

family | model | RMSE | MAE
GPR | GPR_Matern15 | 2.273737209228385e-05 | 1.840865809837095e-05
Polynomial | Poly2_Linear | 0.26981237055609986 | 0.20069459599052078

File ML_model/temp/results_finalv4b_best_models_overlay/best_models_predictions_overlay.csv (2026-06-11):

sample_id | model | family | true | pred | pred_std | abs_error | sq_error
1 | GPR_Matern15 | GPR | 1.0666666666666667 | 1.066708190179642 | 0.00262530791998558 | 4.1523512975372157e-05 | 1.7242021298158999e-09
2 | GPR_Matern15 | GPR | 0.7000000000000001 | 0.699995065132982 | 0.002625436433276756 | 4.934867018024924e-06 | 2.435291248559021e-11
3 | GPR_Matern15 | GPR | 1.6500000000000001 | 1.6499547397414092 | 0.0026252672904275363 | 4.526025859097338e-05 | 2.0484910077217795e-09
4 | GPR_Matern15 | GPR | 1.9000000000000001 | 1.8999956386029668 | 0.0026254200785550135 | 4.361397033303405e-06 | 1.902178408210774e-11
5 | GPR_Matern15 | GPR | 1.9333333333333333 | 1.9333379863107099 | 0.0026254430639814975 | 4.652977376506939e-06 | 2.16501984662854e-11
6 | GPR_Matern15 | GPR | 0.5333333333333333 | 0.533350377583123 | 0.0026254051193811833 | 1.704424978965502e-05 | 2.9050645089215515e-10
7 | GPR_Matern15 | GPR | 3.9 | 3.9000243166553936 | 0.002625385721298294 | 2.4316655393707975e-05 | 5.912997295363472e-10
8 | GPR_Matern15 | GPR | 1.6333333333333335 | 1.633310570142704 | 0.0026253404791465626 | 2.2763190629548902e-05 | 5.18162847637183e-10
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

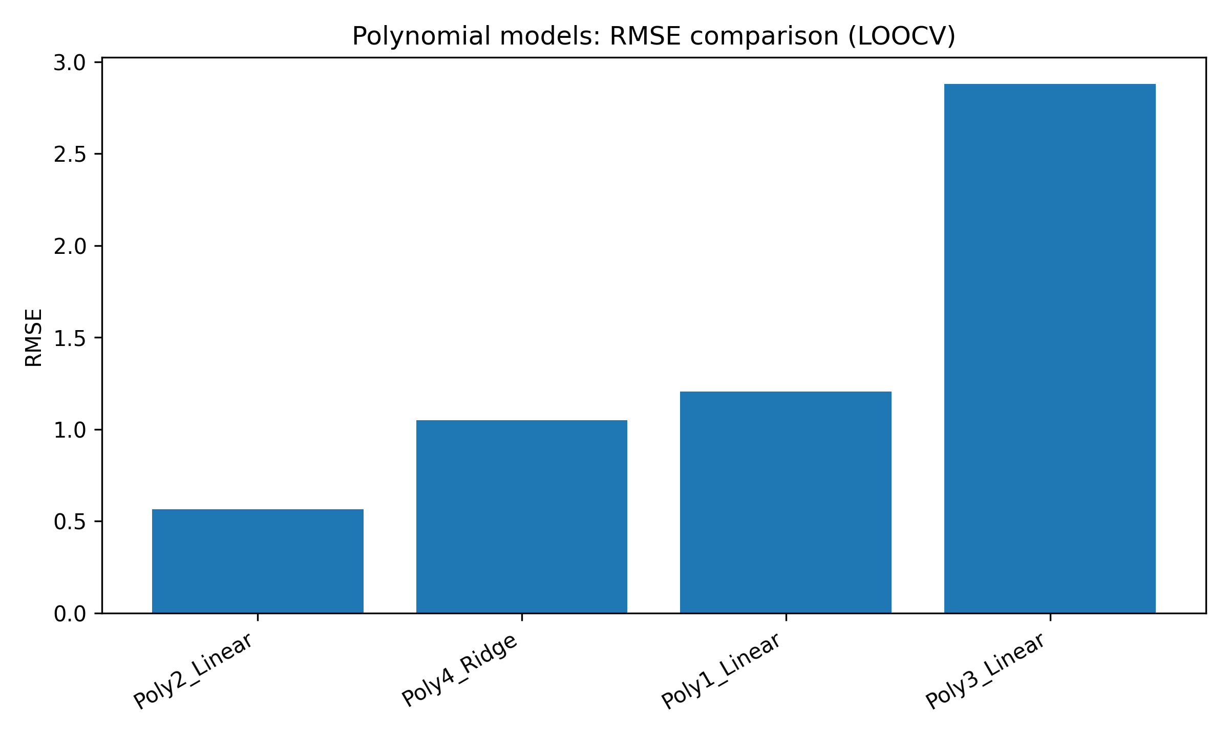
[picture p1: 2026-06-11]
ML_model/temp/results_finalv4b_polynomial_loocv/Fig_Polynomial_RMSE.png

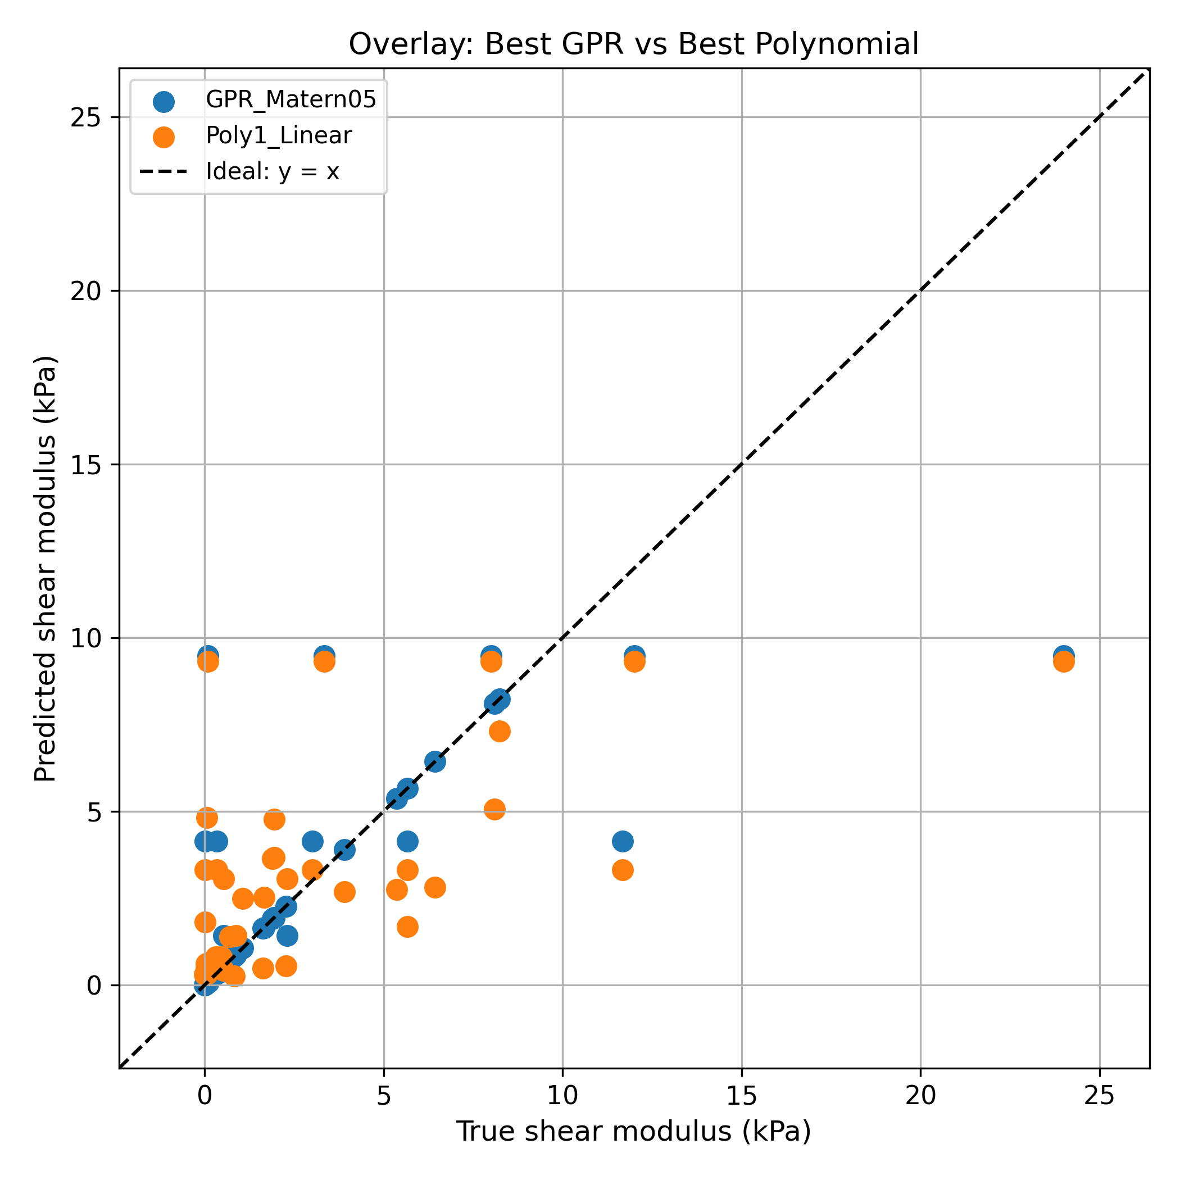
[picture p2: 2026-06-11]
ML_model/temp/results_finalv4c_best_models_overlay/Fig_best_gpr_vs_best_polynomial_overlay_true_vs_pred.png

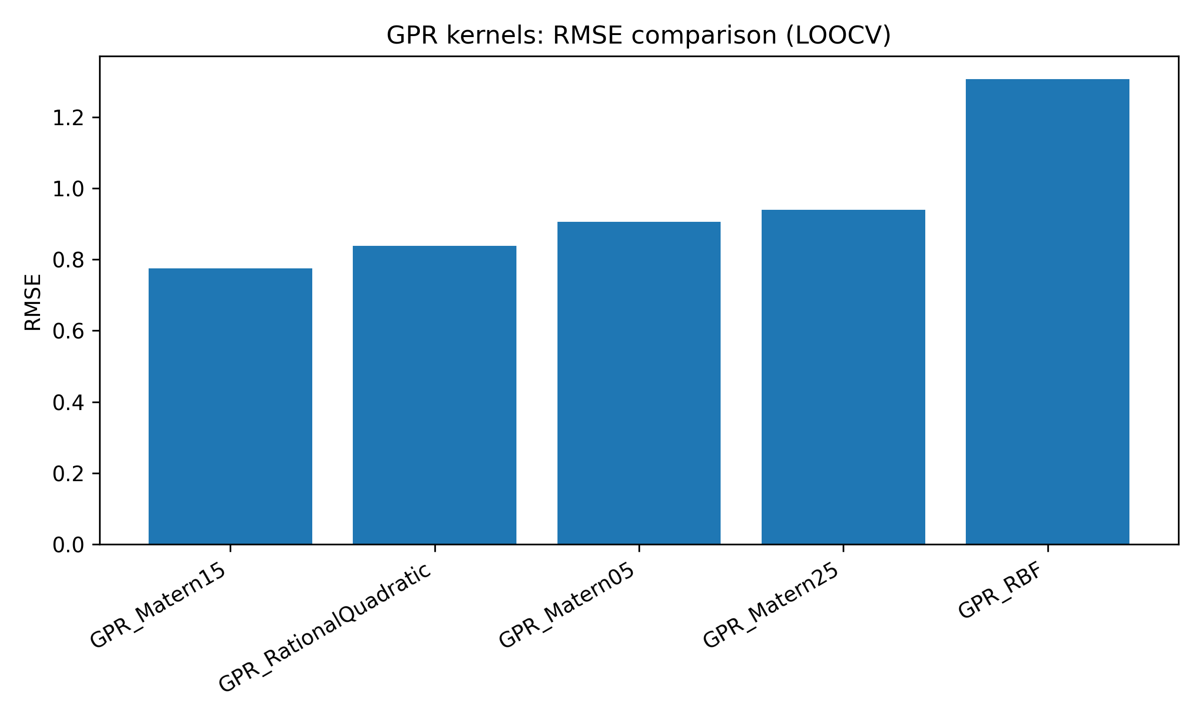
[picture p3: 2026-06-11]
ML_model/temp/results_finalv4b_gpr_loocv/Fig_GPR_RMSE.png

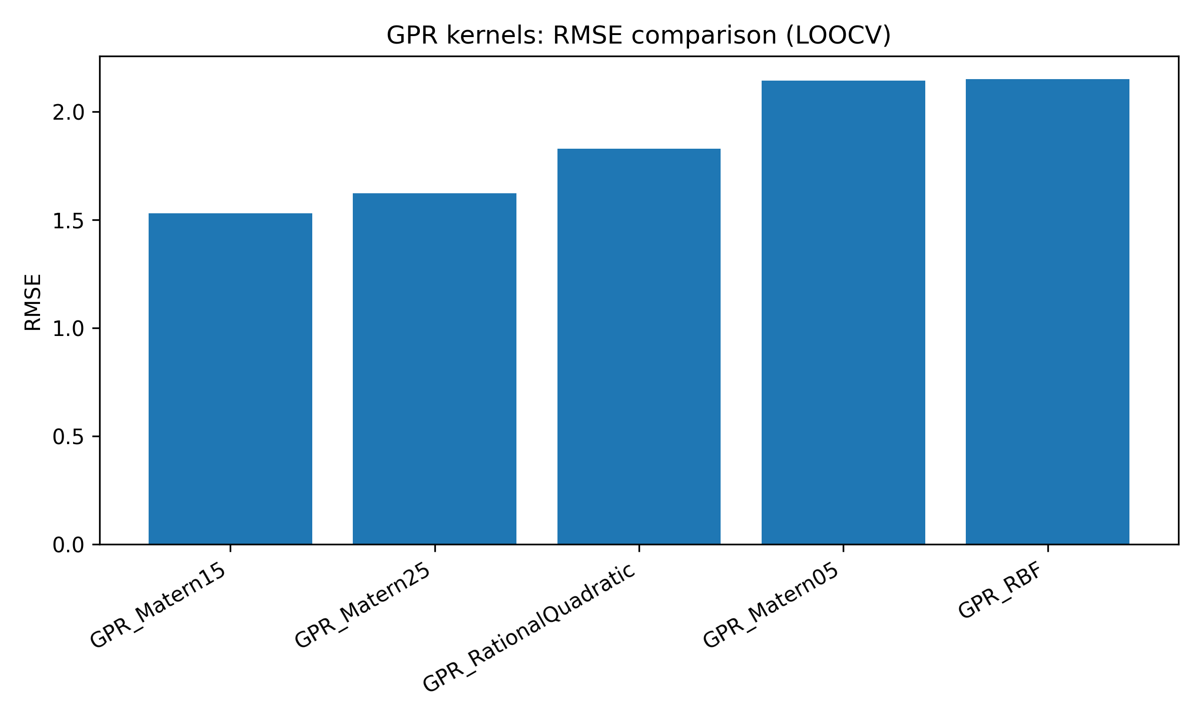
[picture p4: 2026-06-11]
ML_model/temp/results_finalv4a_gpr_loocv/Fig_GPR_RMSE.png

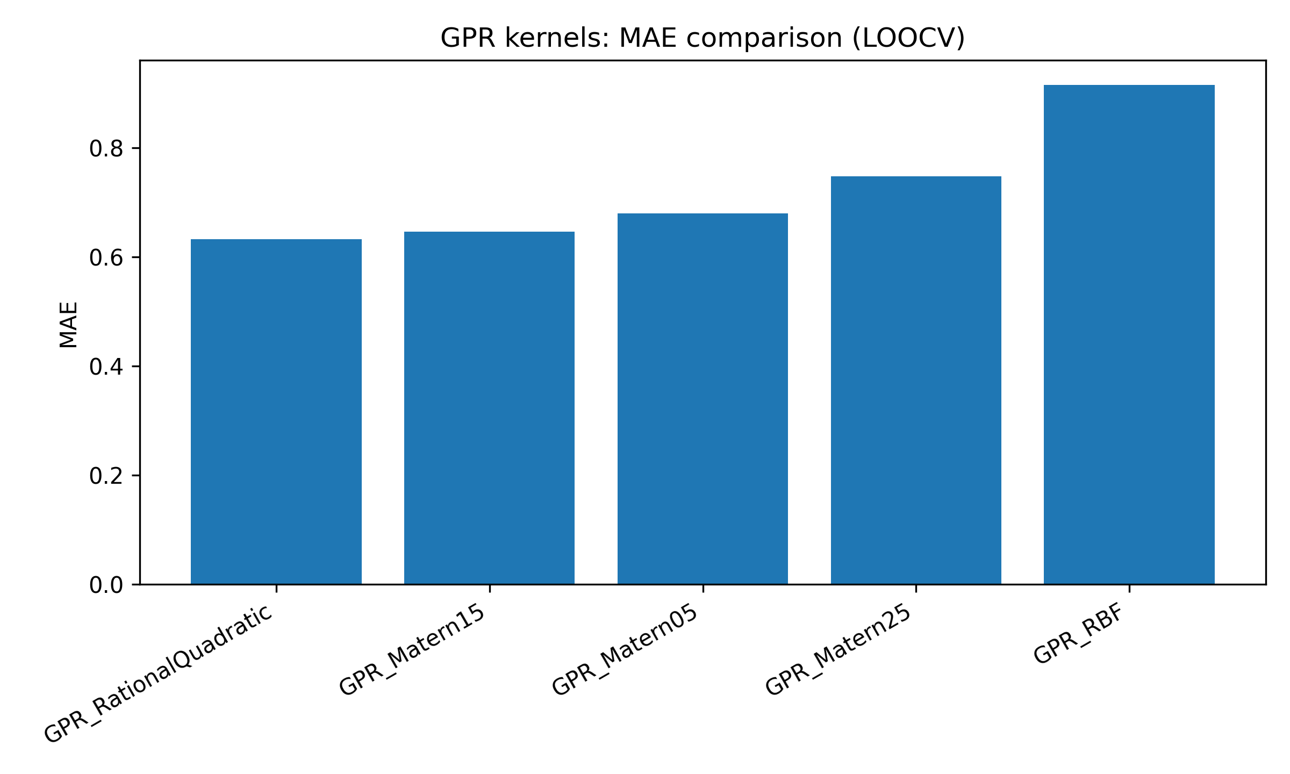
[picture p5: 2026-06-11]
ML_model/temp/results_finalv4b_gpr_loocv/Fig_GPR_MAE.png

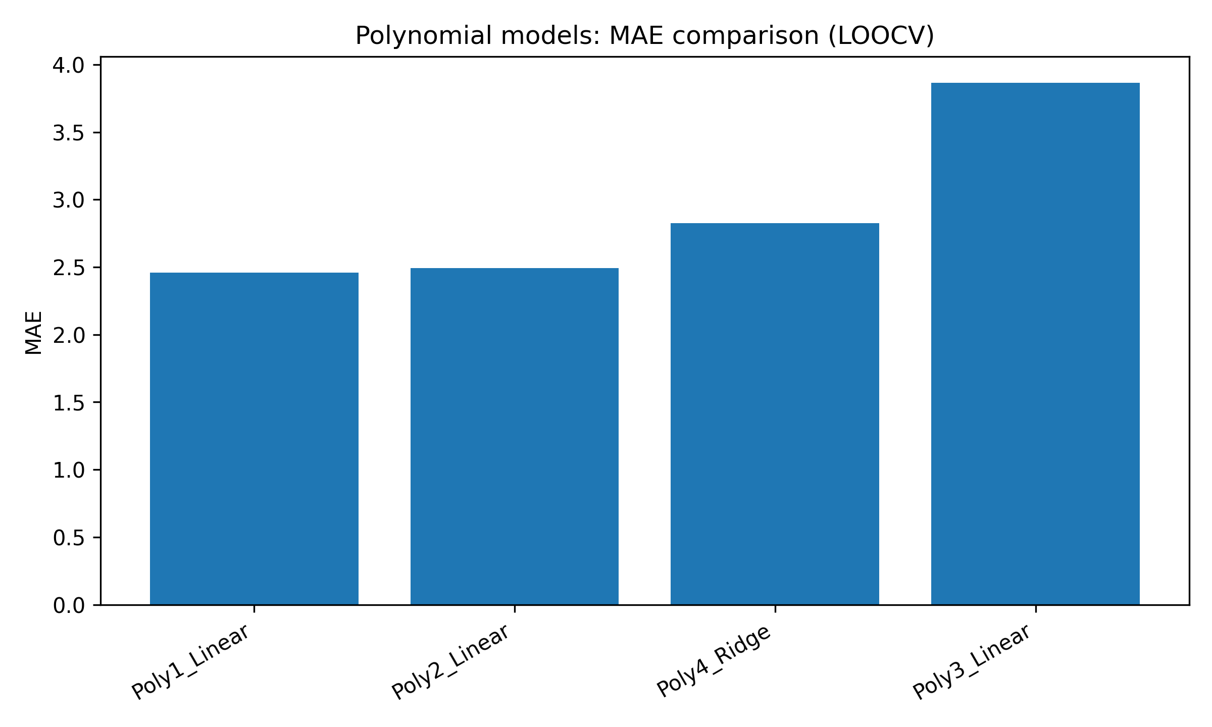
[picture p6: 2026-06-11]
ML_model/temp/results_finalv4c_polynomial_loocv/Fig_Polynomial_MAE.png

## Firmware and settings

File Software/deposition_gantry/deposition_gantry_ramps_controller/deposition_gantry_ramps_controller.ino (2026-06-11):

/*
  Arduino Mega + RAMPS 1.4 gantry + syringe pump controller

  GANTRY module motion model:
    - Both motors same direction: X axis
    - Motors opposite directions: Y axis

  Serial commands, 115200 baud:
    GANTRY SETZERO
    GANTRY SETPOS X30 Y20
    GANTRY GOTO X20 Y30
    GANTRY CIRCLE X30 Y30 R8 N120 L1
    GANTRY SPEED S20
    GANTRY ACCEL S100

    PUMP ZS0.1        Z small syringe, dispense 0.1 ml
    PUMP E1S-0.1      E1 small syringe, aspirate 0.1 ml
    PUMP PAIR ZS0.1 E1S-0.1
    PUMP ZM5          Z calibration move 5 mm
    PUMP E1M-5        E1 calibration move -5 mm
    PUMP SPEED S5     set pump speed to 5 mm/s

    GANTRY DEPOSIT X30 Y30 R8 V0.5 N120 L1

    STOP              emergency stop, disables all motors
    UNLOCK            re-enable after STOP
    HELP              print commands

  Old unprefixed gantry commands still work for compatibility.
*/

// RAMPS 1.4 pinout for X and Y stepper sockets.
const byte MOTOR_A_STEP_PIN = 54;  // RAMPS X_STEP
const byte MOTOR_A_DIR_PIN = 55;   // RAMPS X_DIR
const byte MOTOR_A_EN_PIN = 38;    // RAMPS X_ENABLE, active LOW

const byte MOTOR_B_STEP_PIN = 60;  // RAMPS Y_STEP
const byte MOTOR_B_DIR_PIN = 61;   // RAMPS Y_DIR
const byte MOTOR_B_EN_PIN = 56;    // RAMPS Y_ENABLE, active LOW

const byte Z_PUMP_STEP_PIN = 46;   // RAMPS Z_STEP
const byte Z_PUMP_DIR_PIN = 48;    // RAMPS Z_DIR
const byte Z_PUMP_EN_PIN = 62;     // RAMPS Z_ENABLE, active LOW

const byte E1_PUMP_STEP_PIN = 36;  // RAMPS E1_STEP
const byte E1_PUMP_DIR_PIN = 34;   // RAMPS E1_DIR
const byte E1_PUMP_EN_PIN = 30;    // RAMPS E1_ENABLE, active LOW

// Adjust these first. Start low to avoid over-travel.
const float STEPS_PER_MM_X = 14.5;
const float STEPS_PER_MM_Y = 14.5;
const float MAX_X_MM = 165.0;
const float MAX_Y_MM = 165.0;

// Flip these if an axis moves the wrong way.
const bool INVERT_MOTOR_A_DIR = true;
const bool INVERT_MOTOR_B_DIR = true;
const bool INVERT_X_AXIS = false;
const bool INVERT_Y_AXIS = true;
const bool INVERT_Z_PUMP_DIR = false;
const bool INVERT_E1_PUMP_DIR = false;

// Conservative motion settings inspired by Marlin-style trapezoid planning.
const unsigned int STEP_HIGH_US = 5;
const unsigned int MIN_STEP_INTERVAL_US = 250;
const unsigned int MAX_STEP_INTERVAL_US = 12000;
const float DEFAULT_MAX_FEEDRATE_MM_S = 20.0;
const float DEFAULT_ACCELERATION_MM_S2 = 100.0;
const float START_FEEDRATE_MM_S = 2.0;
const int DEFAULT_CIRCLE_SEGMENTS = 120;
const int MIN_CIRCLE_SEGMENTS = 24;
const int MAX_CIRCLE_SEGMENTS = 360;
const int MAX_CIRCLE_LOOPS = 10;

// Pump settings from the syringe pump sketch.
const float PUMP_MOTOR_STEPS_PER_REV = 200.0;
const float PUMP_MICROSTEPS = 16.0;
const float PUMP_LEADSCREW_MM_PER_REV = 8.0;
const float PUMP_STEPS_PER_MM = (PUMP_MOTOR_STEPS_PER_REV * PUMP_MICROSTEPS) / PUMP_LEADSCREW_MM_PER_REV;
const float SMALL_SYRINGE_MM_PER_ML = 43.0 / 2.0;
const float LARGE_SYRINGE_MM_PER_ML = 89.0 / 10.0;
const float DEFAULT_PUMP_SPEED_MM_S = 5.0;
const float MIN_PUMP_SPEED_MM_S = 0.1;
const float MAX_PUMP_SPEED_MM_S = 20.0;

float currentX = 0.0;
float currentY = 0.0;
float maxFeedrateMmS = DEFAULT_MAX_FEEDRATE_MM_S;
float accelerationMmS2 = DEFAULT_ACCELERATION_MM_S2;
float pumpSpeedMmS = DEFAULT_PUMP_SPEED_MM_S;
bool homed = true;
bool emergencyStop = false;
String inputLine;

struct PumpMotor {
  const char *name;
  byte stepPin;
  byte dirPin;
  byte enPin;
  bool invertDir;
};

PumpMotor zPump = {"Z", Z_PUMP_STEP_PIN, Z_PUMP_DIR_PIN, Z_PUMP_EN_PIN, INVERT_Z_PUMP_DIR};
PumpMotor e1Pump = {"E1", E1_PUMP_STEP_PIN, E1_PUMP_DIR_PIN, E1_PUMP_EN_PIN, INVERT_E1_PUMP_DIR};

void setup() {
  pinMode(MOTOR_A_STEP_PIN, OUTPUT);
  pinMode(MOTOR_A_DIR_PIN, OUTPUT);
  pinMode(MOTOR_A_EN_PIN, OUTPUT);
  pinMode(MOTOR_B_STEP_PIN, OUTPUT);
  pinMode(MOTOR_B_DIR_PIN, OUTPUT);
  pinMode(MOTOR_B_EN_PIN, OUTPUT);
  pinMode(Z_PUMP_STEP_PIN, OUTPUT);
  pinMode(Z_PUMP_DIR_PIN, OUTPUT);
  pinMode(Z_PUMP_EN_PIN, OUTPUT);
  pinMode(E1_PUMP_STEP_PIN, OUTPUT);
  pinMode(E1_PUMP_DIR_PIN, OUTPUT);
  pinMode(E1_PUMP_EN_PIN, OUTPUT);

  disableGantryMotors();
  disablePumpMotor(&zPump);
  disablePumpMotor(&e1Pump);
  Serial.begin(115200);
  delay(800);

  Serial.println(F("RAMPS gantry + pump controller ready."));
  Serial.println(F("Manual zero mode: put gantry at left-bottom before power-up or send SETZERO there."));
  printHelp();
  setZero();
}

void loop() {
  readSerialCommands();
}

void printHelp() {
  Serial.println(F("Modules: GANTRY ... | PUMP ..."));
  Serial.println(F("GANTRY: SETZERO | SETPOS X30 Y20 | GOTO X20 Y30 | X10 Y5 | CIRCLE X30 Y30 R8 N120 L1 | POS | SPEED S20 | ACCEL S100"));
  Serial.println(F("GANTRY: DEPOSIT X30 Y30 R8 V0.5 N120 L1"));
  Serial.println(F("PUMP: ZS0.1 | E1S-0.1 | PAIR ZS0.1 E1S-0.1 | ZL0.1 | E1M5 | SPEED S5 | SETTINGS | ENABLE Z | DISABLE E1"));
  Serial.println(F("Global: STOP | UNLOCK | HELP"));
}

void enableGantryMotors() {
  digitalWrite(MOTOR_A_EN_PIN, LOW);
  digitalWrite(MOTOR_B_EN_PIN, LOW);
}

void disableGantryMotors() {
  digitalWrite(MOTOR_A_EN_PIN, HIGH);
  digitalWrite(MOTOR_B_EN_PIN, HIGH);
}

void enablePumpMotor(PumpMotor *pump) {
  digitalWrite(pump->enPin, LOW);
}

void disablePumpMotor(PumpMotor *pump) {
  digitalWrite(pump->enPin, HIGH);
}

void disableAllMotors() {
  disableGantryMotors();
  disablePumpMotor(&zPump);
  disablePumpMotor(&e1Pump);
}

void setMotorDir(byte dirPin, int dirSign, bool invert) {
  bool level = dirSign >= 0;
  if (invert) {
    level = !level;
  }
  digitalWrite(dirPin, level ? HIGH : LOW);
}

void pulseMotor(byte stepPin) {
  digitalWrite(stepPin, HIGH);
  delayMicroseconds(STEP_HIGH_US);
  digitalWrite(stepPin, LOW);
}

void pulseBoth(bool stepA, bool stepB) {
  if (stepA) {
    digitalWrite(MOTOR_A_STEP_PIN, HIGH);
  }
  if (stepB) {
    digitalWrite(MOTOR_B_STEP_PIN, HIGH);
  }
  delayMicroseconds(STEP_HIGH_US);
  if (stepA) {
    digitalWrite(MOTOR_A_STEP_PIN, LOW);
  }
  if (stepB) {
    digitalWrite(MOTOR_B_STEP_PIN, LOW);
  }
}

bool checkStopRequest() {
  while (Serial.available() > 0) {
    char c = Serial.read();
    if (c == '\n' || c == '\r') {
      inputLine.trim();
      inputLine.toUpperCase();
      if (inputLine == "STOP") {
        emergencyStop = true;
        disableAllMotors();
        Serial.println(F("EMERGENCY STOP. Send UNLOCK to continue."));
      }
      inputLine = "";
    } else {
      inputLine += c;
      if (inputLine.length() > 80) {
        inputLine = "";
      }
    }
  }
  return emergencyStop;
}

void readSerialCommands() {
  while (Serial.available() > 0) {
    char c = Serial.read();
    if (c == '\n' || c == '\r') {
      inputLine.trim();
      if (inputLine.length() > 0) {
        handleCommand(inputLine);
      }
      inputLine = "";
    } else {
      inputLine += c;
      if (inputLine.length() > 80) {
        inputLine = "";
      }
    }
  }
}

bool extractValue(String cmd, char key, float &value) {
  int i = cmd.lastIndexOf(key);
  if (i < 0) {
    return false;
  }

  int start = i + 1;
  while (start < cmd.length() && cmd[start] == ' ') {
    start++;
  }

  int end = start;
  while (end < cmd.length()) {
    char c = cmd[end];
    if ((c >= '0' && c <= '9') || c == '-' || c == '+' || c == '.') {
      end++;
    } else {
      break;
    }
  }

  if (end == start) {
    return false;
  }

  value = cmd.substring(start, end).toFloat();
  return true;
}

void handleCommand(String cmd) {
  cmd.trim();
  cmd.toUpperCase();

  if (cmd == "STOP") {
    emergencyStop = true;
    disableAllMotors();
    Serial.println(F("EMERGENCY STOP. Send UNLOCK to continue."));
    return;
  }

  if (cmd == "UNLOCK") {
    emergencyStop = false;
    Serial.println(F("Unlocked."));
    Serial.println(F("OK"));
    return;
  }

  if (cmd == "HELP") {
    printHelp();
    return;
  }

  if (cmd.startsWith("GANTRY ")) {
    handleGantryCommand(cmd.substring(7));
    return;
  }

  if (cmd.startsWith("G ")) {
    handleGantryCommand(cmd.substring(2));
    return;
  }

  if (cmd.startsWith("PUMP ")) {
    handlePumpCommand(cmd.substring(5));
    return;
  }

  if (cmd.startsWith("P ")) {
    handlePumpCommand(cmd.substring(2));
    return;
  }

  if (cmd.startsWith("Z") || cmd.startsWith("E1")) {
    handlePumpCommand(cmd);
    return;
  }

  handleGantryCommand(cmd);
}

void handleGantryCommand(String cmd) {
  cmd.trim();
  cmd.toUpperCase();

  if (cmd == "POS") {
    printPosition();
    return;
  }

  if (cmd == "SETTINGS") {
    printSettings();
    Serial.println(F("OK"));
    return;
  }

  if (emergencyStop) {
    Serial.println(F("Stopped. Send UNLOCK to continue."));
    return;
  }

  if (cmd == "HOME" || cmd == "SETZERO") {
    setZero();
    Serial.println(F("OK"));
    return;
  }

  if (cmd.startsWith("SETPOS")) {
    handleSetPosition(cmd);
    return;
  }

  if (cmd.startsWith("SPEED")) {
    float value = 0.0;
    if (extractValue(cmd, 'S', value) && value >= 1.0 && value <= 80.0) {
      maxFeedrateMmS = value;
      printSettings();
      Serial.println(F("OK"));
    } else {
      Serial.println(F("Use SPEED S1..S80"));
    }
    return;
  }

  if (cmd.startsWith("ACCEL")) {
    float value = 0.0;
    if (extractValue(cmd, 'S', value) && value >= 10.0 && value <= 1000.0) {
      accelerationMmS2 = value;
      printSettings();
      Serial.println(F("OK"));
    } else {
      Serial.println(F("Use ACCEL S10..S1000"));
    }
    return;
  }

  if (cmd.startsWith("CIRCLE")) {
    handleCircleCommand(cmd);
    return;
  }

  if (cmd.startsWith("DEPOSIT")) {
    handleDepositCommand(cmd);
    return;
  }

  float xValue = 0.0;
  float yValue = 0.0;
  bool hasX = extractValue(cmd, 'X', xValue);
  bool hasY = extractValue(cmd, 'Y', yValue);

  if (!hasX && !hasY) {
    Serial.println(F("Unknown command. Send HELP."));
    return;
  }

  if (!homed) {
    Serial.println(F("Position is not set. Move to left-bottom and send SETZERO."));
    return;
  }

  float targetX = currentX;
  float targetY = currentY;

  if (cmd.startsWith("GOTO")) {
    if (hasX) {
      targetX = xValue;
    }
    if (hasY) {
      targetY = yValue;
    }
  } else {
    if (hasX) {
      targetX += xValue;
    }
    if (hasY) {
      targetY += yValue;
    }
  }

  moveTo(targetX, targetY, true);
}

void printPosition() {
  Serial.print(F("POS X"));
  Serial.print(currentX, 3);
  Serial.print(F(" Y"));
  Serial.print(currentY, 3);
  Serial.print(F(" homed="));
  Serial.println(homed ? F("yes") : F("no"));
}

void handleSetPosition(String cmd) {
  float xValue = currentX;
  float yValue = currentY;
  bool hasX = extractValue(cmd, 'X', xValue);
  bool hasY = extractValue(cmd, 'Y', yValue);

  if (!hasX && !hasY) {
    Serial.println(F("Use SETPOS Xvalue Yvalue"));
    return;
  }
  if (!withinLimits(xValue, yValue)) {
    Serial.println(F("SETPOS rejected: outside soft limits."));
    return;
  }

  currentX = xValue;
  currentY = yValue;
  homed = true;
  Serial.println(F("Logical position updated without movement."));
  printPosition();
  Serial.println(F("OK"));
}

void printSettings() {
  Serial.print(F("SETTINGS speed="));
  Serial.print(maxFeedrateMmS, 2);
  Serial.print(F("mm/s accel="));
  Serial.print(accelerationMmS2, 2);
  Serial.println(F("mm/s^2"));
}

void printPumpSettings() {
  Serial.print(F("PUMP SETTINGS speed="));
  Serial.print(pumpSpeedMmS, 3);
  Serial.print(F("mm/s stepsPerMm="));
  Serial.print(PUMP_STEPS_PER_MM, 3);
  Serial.print(F(" smallMmPerMl="));
  Serial.print(SMALL_SYRINGE_MM_PER_ML, 3);
  Serial.println();
  Serial.println(F("OK"));
}

PumpMotor *findPumpMotor(String cmd, int &prefixLength) {
  cmd.trim();
  cmd.toUpperCase();

  if (cmd.startsWith("E1")) {
    prefixLength = 2;
    return &e1Pump;
  }

  if (cmd.startsWith("Z")) {
    prefixLength = 1;
    return &zPump;
  }

  prefixLength = 0;
  return NULL;
}

void setPumpDir(PumpMotor *pump, int dirSign) {
  bool level = dirSign >= 0;
  if (pump->invertDir) {
    level = !level;
  }
  digitalWrite(pump->dirPin, level ? HIGH : LOW);
}

unsigned int pumpStepIntervalUs() {
  float stepsPerSecond = pumpSpeedMmS * PUMP_STEPS_PER_MM;
  if (stepsPerSecond < 1.0) {
    stepsPerSecond = 1.0;
  }

  float interval = 1000000.0 / stepsPerSecond;
  if (interval < 250.0) {
    interval = 250.0;
  }
  if (interval > 30000.0) {
    interval = 30000.0;
  }
  return (unsigned int)interval;
}

long pumpMmToSteps(float mm) {
  float steps = mm * PUMP_STEPS_PER_MM;
  return steps >= 0.0 ? (long)(steps + 0.5) : (long)(steps - 0.5);
}

float pumpModeValueToMm(char mode, float value) {
  if (mode == 'S') {
    return value * SMALL_SYRINGE_MM_PER_ML;
  }
  if (mode == 'L') {
    return value * LARGE_SYRINGE_MM_PER_ML;
  }
  if (mode == 'M') {
    return value;
  }
  return 0.0;
}

void runPumpMove(PumpMotor *pump, float mm) {
  long steps = pumpMmToSteps(mm);
  long absSteps = labs(steps);

  if (absSteps == 0) {
    Serial.println(F("Pump move rounded to 0 steps."));
    Serial.println(F("OK"));
    return;
  }

  enablePumpMotor(pump);
  setPumpDir(pump, steps >= 0 ? 1 : -1);

  unsigned int intervalUs = pumpStepIntervalUs();
  for (long i = 0; i < absSteps; i++) {
    if (checkStopRequest()) {
      return;
    }
    digitalWrite(pump->stepPin, HIGH);
    delayMicroseconds(STEP_HIGH_US);
    digitalWrite(pump->stepPin, LOW);
    delayMicroseconds(intervalUs);
  }

  Serial.print(F("PUMP "));
  Serial.print(pump->name);
  Serial.print(F(" move "));
  Serial.print(mm, 4);
  Serial.print(F(" mm, steps "));
  Serial.println(absSteps);
  Serial.println(F("OK"));
}

void pulsePumpPair(bool stepA, byte stepPinA, bool stepB, byte stepPinB) {
  if (stepA) {
    digitalWrite(stepPinA, HIGH);
  }
  if (stepB) {
    digitalWrite(stepPinB, HIGH);
  }
  delayMicroseconds(STEP_HIGH_US);
  if (stepA) {
    digitalWrite(stepPinA, LOW);
  }
  if (stepB) {
    digitalWrite(stepPinB, LOW);
  }
}

void runPumpPairMove(PumpMotor *pumpA, float mmA, PumpMotor *pumpB, float mmB) {
  if (pumpA == pumpB) {
    Serial.println(F("PAIR rejected: use two different pump motors."));
    return;
  }

  long stepsA = pumpMmToSteps(mmA);
  long stepsB = pumpMmToSteps(mmB);
  long absA = labs(stepsA);
  long absB = labs(stepsB);
  long total = max(absA, absB);

  if (total == 0) {
    Serial.println(F("PAIR move rounded to 0 steps."));
    Serial.println(F("OK"));
    return;
  }

  enablePumpMotor(pumpA);
  enablePumpMotor(pumpB);
  setPumpDir(pumpA, stepsA >= 0 ? 1 : -1);
  setPumpDir(pumpB, stepsB >= 0 ? 1 : -1);

  unsigned int intervalUs = pumpStepIntervalUs();
  long errorA = 0;
  long errorB = 0;

  for (long i = 0; i < total; i++) {
    if (checkStopRequest()) {
      return;
    }

    errorA += absA;
    errorB += absB;

    bool stepA = false;
    bool stepB = false;

    if (errorA >= total) {
      errorA -= total;
      stepA = true;
    }
    if (errorB >= total) {
      errorB -= total;
      stepB = true;
    }

    pulsePumpPair(stepA, pumpA->stepPin, stepB, pumpB->stepPin);
    delayMicroseconds(intervalUs);
  }

  Serial.print(F("PUMP PAIR "));
  Serial.print(pumpA->name);
  Serial.print(F(" "));
  Serial.print(mmA, 4);
  Serial.print(F(" mm, "));
  Serial.print(pumpB->name);
  Serial.print(F(" "));
  Serial.print(mmB, 4);
  Serial.println(F(" mm"));
  Serial.println(F("OK"));
}

bool parsePumpMoveSpec(String spec, PumpMotor *&pump, float &mm) {
  spec.trim();
  spec.toUpperCase();

  int prefixLength = 0;
  pump = findPumpMotor(spec, prefixLength);
  if (pump == NULL) {
    return false;
  }

  String payload = spec.substring(prefixLength);
  payload.trim();
  if (payload.length() < 2) {
    return false;
  }

  char mode = payload.charAt(0);
  float value = payload.substring(1).toFloat();
  if (mode != 'S' && mode != 'L' && mode != 'M') {
    return false;
  }

  mm = pumpModeValueToMm(mode, value);
  return true;
}

void handlePumpPairCommand(String cmd) {
  String payload = cmd;
  payload.trim();

  int spaceIndex = payload.indexOf(' ');
  if (spaceIndex < 0) {
    Serial.println(F("Use PUMP PAIR ZS0.1 E1S-0.1"));
    return;
  }

  String first = payload.substring(0, spaceIndex);
  String second = payload.substring(spaceIndex + 1);
  first.trim();
  second.trim();

  PumpMotor *pumpA = NULL;
  PumpMotor *pumpB = NULL;
  float mmA = 0.0;
  float mmB = 0.0;

  if (!parsePumpMoveSpec(first, pumpA, mmA) || !parsePumpMoveSpec(second, pumpB, mmB)) {
    Serial.println(F("Use PUMP PAIR ZS0.1 E1S-0.1"));
    return;
  }

  runPumpPairMove(pumpA, mmA, pumpB, mmB);
}

void handlePumpCommand(String cmd) {
  cmd.trim();
  cmd.toUpperCase();

  if (emergencyStop) {
    Serial.println(F("Stopped. Send UNLOCK to continue."));
    return;
  }

  if (cmd == "SETTINGS") {
    printPumpSettings();
    return;
  }

  if (cmd.startsWith("PAIR ")) {
    handlePumpPairCommand(cmd.substring(5));
    return;
  }

  if (cmd.startsWith("SPEED")) {
    float value = 0.0;
    if (extractValue(cmd, 'S', value) && value >= MIN_PUMP_SPEED_MM_S && value <= MAX_PUMP_SPEED_MM_S) {
      pumpSpeedMmS = value;
      printPumpSettings();
    } else {
      Serial.println(F("Use PUMP SPEED S0.1..S20"));
    }
    return;
  }

  if (cmd.startsWith("ENABLE ") || cmd.startsWith("DISABLE ")) {
    bool shouldEnable = cmd.startsWith("ENABLE ");
    String motorText = cmd.substring(shouldEnable ? 7 : 8);
    motorText.trim();

    int utilityPrefixLength = 0;
    PumpMotor *utilityPump = findPumpMotor(motorText, utilityPrefixLength);
    if (utilityPump == NULL || utilityPrefixLength != motorText.length()) {
      Serial.println(F("Unknown pump motor. Use Z or E1."));
      return;
    }

    if (shouldEnable) {
      enablePumpMotor(utilityPump);
      Serial.print(F("PUMP "));
      Serial.print(utilityPump->name);
      Serial.println(F(" enabled."));
    } else {
      disablePumpMotor(utilityPump);
      Serial.print(F("PUMP "));
      Serial.print(utilityPump->name);
      Serial.println(F(" disabled."));
    }
    Serial.println(F("OK"));
    return;
  }

  int prefixLength = 0;
  PumpMotor *pump = findPumpMotor(cmd, prefixLength);
  if (pump == NULL) {
    Serial.println(F("Unknown pump motor. Use Z or E1."));
    return;
  }

  String payload = cmd.substring(prefixLength);
  payload.trim();

  if (payload == "ENABLE") {
    enablePumpMotor(pump);
    Serial.print(F("PUMP "));
    Serial.print(pump->name);
    Serial.println(F(" enabled."));
    Serial.println(F("OK"));
    return;
  }

  if (payload == "DISABLE") {
    disablePumpMotor(pump);
    Serial.print(F("PUMP "));
    Serial.print(pump->name);
    Serial.println(F(" disabled."));
    Serial.println(F("OK"));
    return;
  }

  if (payload.length() < 2) {
    Serial.println(F("Use PUMP ZS0.1, PUMP E1S-0.1, PUMP ZM5, or PUMP SPEED S5."));
    return;
  }

  char mode = payload.charAt(0);
  float value = payload.substring(1).toFloat();

  if (mode == 'S') {
    runPumpMove(pump, pumpModeValueToMm(mode, value));
    return;
  }

  if (mode == 'L') {
    runPumpMove(pump, pumpModeValueToMm(mode, value));
    return;
  }

  if (mode == 'M') {
    runPumpMove(pump, pumpModeValueToMm(mode, value));
    return;
  }

  Serial.println(F("Unknown pump mode. Use S for small ml, L for large ml, or M for mm."));
}

bool withinLimits(float x, float y) {
  return x >= 0.0 && x <= MAX_X_MM && y >= 0.0 && y <= MAX_Y_MM;
}

long mmToSteps(float mm, float stepsPerMm) {
  float steps = mm * stepsPerMm;
  return steps >= 0.0 ? (long)(steps + 0.5) : (long)(steps - 0.5);
}

void moveTo(float targetX, float targetY, bool reportPosition) {
  if (!withinLimits(targetX, targetY)) {
    Serial.println(F("Move rejected: outside soft limits."));
    return;
  }

  float dxMm = targetX - currentX;
  float dyMm = targetY - currentY;
  if (INVERT_X_AXIS) {
    dxMm = -dxMm;
  }
  if (INVERT_Y_AXIS) {
    dyMm = -dyMm;
  }

  float pathMm = sqrt(dxMm * dxMm + dyMm * dyMm);
  long xSteps = mmToSteps(dxMm, STEPS_PER_MM_X);
  long ySteps = mmToSteps(dyMm, STEPS_PER_MM_Y);

  // Motor transform: A = X + Y, B = X - Y.
  long aSteps = xSteps + ySteps;
  long bSteps = xSteps - ySteps;

  runMotorSteps(aSteps, bSteps, pathMm);

  if (!emergencyStop) {
    currentX = targetX;
    currentY = targetY;
    if (reportPosition) {
      printPosition();
      Serial.println(F("OK"));
    }
  }
}
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

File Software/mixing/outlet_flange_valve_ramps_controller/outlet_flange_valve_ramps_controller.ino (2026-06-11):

/*
  Arduino Mega + RAMPS 1.4 Z flange controller

  Hardware:
    - Arduino Mega 2560
    - RAMPS 1.4
    - Z driver socket with TMC2208 in standalone STEP/DIR mode

  Serial commands, 115200 baud:
    UP          move one calibrated height upward
    DOWN        move one calibrated height downward
    MIX_X_CW90  rotate the X-area mixing valve motor one quarter turn clockwise
    MIX_X_CCW90 rotate the X-area mixing valve motor one quarter turn counter-clockwise
    MIX_Y_CW180 rotate the Y-area mixing valve motor one half turn clockwise
    MIX_Y_CCW180 rotate the Y-area mixing valve motor one half turn counter-clockwise
    STOP        immediately stop stepping and disable Z driver power
    ENABLE      enable Z driver power without moving
    ON          same as ENABLE
    UNLOCK      clear stop state and enable Z driver power
    OFF         disable Z driver power without changing stop state
    STATUS      print motor power and stop state
    SETTINGS    print motion settings
    HELP        print commands

  This firmware deliberately uses direct stepping instead of AccelStepper so
  STOP can be detected during a blocking move, matching the gantry controller.
*/

const byte Z_STEP_PIN = 46;    // RAMPS Z_STEP
const byte Z_DIR_PIN = 48;     // RAMPS Z_DIR
const byte Z_ENABLE_PIN = 62;  // RAMPS Z_ENABLE, active LOW

const byte X_STEP_PIN = 54;    // RAMPS X_STEP
const byte X_DIR_PIN = 55;     // RAMPS X_DIR
const byte X_ENABLE_PIN = 38;  // RAMPS X_ENABLE, active LOW

const byte Y_STEP_PIN = 60;    // RAMPS Y_STEP
const byte Y_DIR_PIN = 61;     // RAMPS Y_DIR
const byte Y_ENABLE_PIN = 56;  // RAMPS Y_ENABLE, active LOW

// Calibrate these for your screw, motor, and TMC2208 microstep setting.
const long HEIGHT_TRAVEL_STEPS = 6400L;
const long MIX_VALVE_QUARTER_TURN_STEPS = 400L;
const long MIX_VALVE_HALF_TURN_STEPS = MIX_VALVE_QUARTER_TURN_STEPS * 2L;
const unsigned int STEP_HIGH_US = 5;
const unsigned int MIN_STEP_INTERVAL_US = 500;
const unsigned int MAX_STEP_INTERVAL_US = 8000;
const float DEFAULT_MAX_SPEED_STEPS_S = 1200.0;
const float DEFAULT_ACCEL_STEPS_S2 = 800.0;
const float START_SPEED_STEPS_S = 150.0;
const float MIX_VALVE_MAX_SPEED_STEPS_S = 700.0;
const float MIX_VALVE_ACCEL_STEPS_S2 = 500.0;

// Flip if UP and DOWN are reversed.
const bool INVERT_Z_DIR = false;
const bool INVERT_X_VALVE_DIR = true;
const bool INVERT_Y_VALVE_DIR = false;

String inputLine;
bool emergencyStop = false;
bool motorEnabled = false;
bool xValveEnabled = false;
bool yValveEnabled = false;
float maxSpeedStepsS = DEFAULT_MAX_SPEED_STEPS_S;
float accelStepsS2 = DEFAULT_ACCEL_STEPS_S2;

void setup() {
  pinMode(Z_STEP_PIN, OUTPUT);
  pinMode(Z_DIR_PIN, OUTPUT);
  pinMode(Z_ENABLE_PIN, OUTPUT);
  pinMode(X_STEP_PIN, OUTPUT);
  pinMode(X_DIR_PIN, OUTPUT);
  pinMode(X_ENABLE_PIN, OUTPUT);
  pinMode(Y_STEP_PIN, OUTPUT);
  pinMode(Y_DIR_PIN, OUTPUT);
  pinMode(Y_ENABLE_PIN, OUTPUT);

  digitalWrite(Z_STEP_PIN, LOW);
  digitalWrite(Z_DIR_PIN, LOW);
  digitalWrite(X_STEP_PIN, LOW);
  digitalWrite(X_DIR_PIN, LOW);
  digitalWrite(Y_STEP_PIN, LOW);
  digitalWrite(Y_DIR_PIN, LOW);
  disableMotor();
  disableXValveMotor();
  disableYValveMotor();

  Serial.begin(115200);
  delay(800);

  Serial.println(F("RAMPS Z flange ready."));
  printHelp();
}

void loop() {
  readSerialCommands();
}

void printHelp() {
  Serial.println(F("Commands: UP | DOWN | MIX_X_CW90 | MIX_X_CCW90 | MIX_Y_CW180 | MIX_Y_CCW180 | STOP | ENABLE | ON | UNLOCK | OFF | STATUS | SETTINGS | HELP"));
}

void enableMotor() {
  digitalWrite(Z_ENABLE_PIN, LOW);
  motorEnabled = true;
}

void disableMotor() {
  digitalWrite(Z_ENABLE_PIN, HIGH);
  motorEnabled = false;
}

void enableXValveMotor() {
  digitalWrite(X_ENABLE_PIN, LOW);
  xValveEnabled = true;
}

void disableXValveMotor() {
  digitalWrite(X_ENABLE_PIN, HIGH);
  xValveEnabled = false;
}

void enableYValveMotor() {
  digitalWrite(Y_ENABLE_PIN, LOW);
  yValveEnabled = true;
}

void disableYValveMotor() {
  digitalWrite(Y_ENABLE_PIN, HIGH);
  yValveEnabled = false;
}

void disableAllMotors() {
  disableMotor();
  disableXValveMotor();
  disableYValveMotor();
}

void setDirection(bool up) {
  bool level = up;
  if (INVERT_Z_DIR) {
    level = !level;
  }
  digitalWrite(Z_DIR_PIN, level ? HIGH : LOW);
}

void pulseStep() {
  digitalWrite(Z_STEP_PIN, HIGH);
  delayMicroseconds(STEP_HIGH_US);
  digitalWrite(Z_STEP_PIN, LOW);
}

void pulseStepPin(byte stepPin) {
  digitalWrite(stepPin, HIGH);
  delayMicroseconds(STEP_HIGH_US);
  digitalWrite(stepPin, LOW);
}

void readSerialCommands() {
  while (Serial.available() > 0) {
    char c = Serial.read();
    if (c == '\n' || c == '\r') {
      inputLine.trim();
      if (inputLine.length() > 0) {
        handleCommand(inputLine);
      }
      inputLine = "";
    } else {
      inputLine += c;
      if (inputLine.length() > 80) {
        inputLine = "";
      }
    }
  }
}

bool checkStopRequest() {
  while (Serial.available() > 0) {
    char c = Serial.read();
    if (c == '\n' || c == '\r') {
      inputLine.trim();
      inputLine.toUpperCase();
      if (inputLine == "STOP") {
        emergencyStop = true;
        disableAllMotors();
        Serial.println(F("EMERGENCY STOP. Motor power off. Send ENABLE or UNLOCK to continue."));
      }
      inputLine = "";
    } else {
      inputLine += c;
      if (inputLine.length() > 80) {
        inputLine = "";
      }
    }
  }
  return emergencyStop;
}

void handleCommand(String cmd) {
  cmd.trim();
  cmd.toUpperCase();

  if (cmd == "STOP") {
    emergencyStop = true;
    disableAllMotors();
    Serial.println(F("EMERGENCY STOP. Motor power off. Send ENABLE or UNLOCK to continue."));
    return;
  }

  if (cmd == "ENABLE" || cmd == "ON" || cmd == "UNLOCK") {
    emergencyStop = false;
    enableMotor();
    Serial.println(F("Motor power on."));
    Serial.println(F("OK"));
    return;
  }

  if (cmd == "OFF") {
    disableAllMotors();
    Serial.println(F("Motor power off."));
    Serial.println(F("OK"));
    return;
  }

  if (cmd == "HELP") {
    printHelp();
    return;
  }

  if (cmd == "STATUS") {
    printStatus();
    Serial.println(F("OK"));
    return;
  }

  if (cmd == "SETTINGS") {
    printSettings();
    Serial.println(F("OK"));
    return;
  }

  if (emergencyStop) {
    Serial.println(F("Stopped. Send ENABLE or UNLOCK to continue."));
    return;
  }

  if (cmd == "UP") {
    moveHeight(true);
    return;
  }

  if (cmd == "DOWN") {
    moveHeight(false);
    return;
  }

  if (cmd == "MIX_X_CW90") {
    moveMixValve('X', true, MIX_VALVE_QUARTER_TURN_STEPS);
    return;
  }

  if (cmd == "MIX_X_CCW90") {
    moveMixValve('X', false, MIX_VALVE_QUARTER_TURN_STEPS);
    return;
  }

  if (cmd == "MIX_Y_CW180") {
    moveMixValve('Y', true, MIX_VALVE_HALF_TURN_STEPS);
    return;
  }

  if (cmd == "MIX_Y_CCW180") {
    moveMixValve('Y', false, MIX_VALVE_HALF_TURN_STEPS);
    return;
  }

  Serial.println(F("Unknown command. Send HELP."));
}
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

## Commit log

2026-06-11 Add project documents and update README
    [Unused Material List.xlsx]
2026-06-11 full version
    [Poly1_Linear_coefficients_raw_basis.csv, Poly1_Linear_coefficients_raw_basis_sorted.csv, Poly1_Linear_coefficients_standardized_basis.csv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]
